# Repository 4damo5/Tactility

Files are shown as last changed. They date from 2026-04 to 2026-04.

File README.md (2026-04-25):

# Tactility: The Portable Braille Reader
*Knowledge at Your Fingertips* · Forge Hardware Spring 2026 · Northeastern University

---

Tactility is a handheld Braille reading device that converts digital text into tactile output in real time. Existing refreshable Braille displays cost hundreds to thousands of dollars and are rarely portable, while Tactility is designed to be compact and affordable.

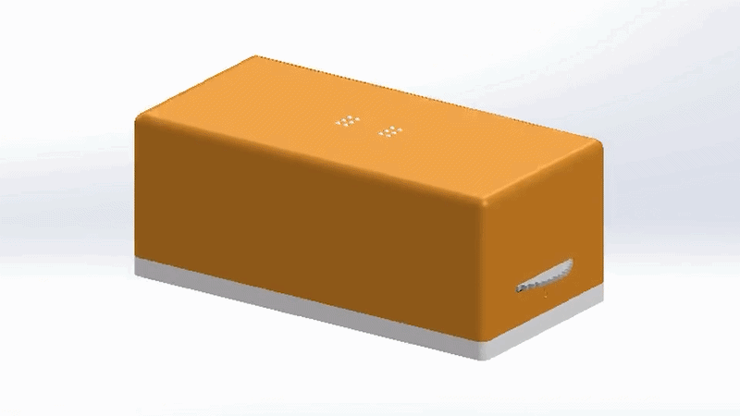
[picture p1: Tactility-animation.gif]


## The Team

| Name | Team |
|---|---|
| Adam Otsuka | Lead |
| Alexandre Lannibois | ECE |
| Daniel Brightman | ECE |
| Ibrahim Rogers | ME |
| Mary Morris | ECE |
| Ryan Heberlig | ME |
| Supratim Shaud | ME |

## How It Works

A rack-and-pinion mechanism drives 6 pins per Braille cell using N20 gearbox motors. An ESP32 microcontroller runs a PDF → text → Braille pipeline, mapping each character to a 6-pin binary array and actuating the motors accordingly. Navigation is handled via scroll wheel, push buttons, and vibration feedback. The PCB was designed in Altium.

## Prototypes

Five iterations were built over the semester, starting with a breadboard proof-of-concept and ending with a 2-cell showcase model with a custom PCB. The ideal form factor is a snap-fit handheld case with Tactility's orange-and-white branding.

## Future Work

- Electromagnetic pin system for a smaller footprint
- MagSafe induction charging for single-hand use
- Phone case form factor
- Companion app for cross-platform text input

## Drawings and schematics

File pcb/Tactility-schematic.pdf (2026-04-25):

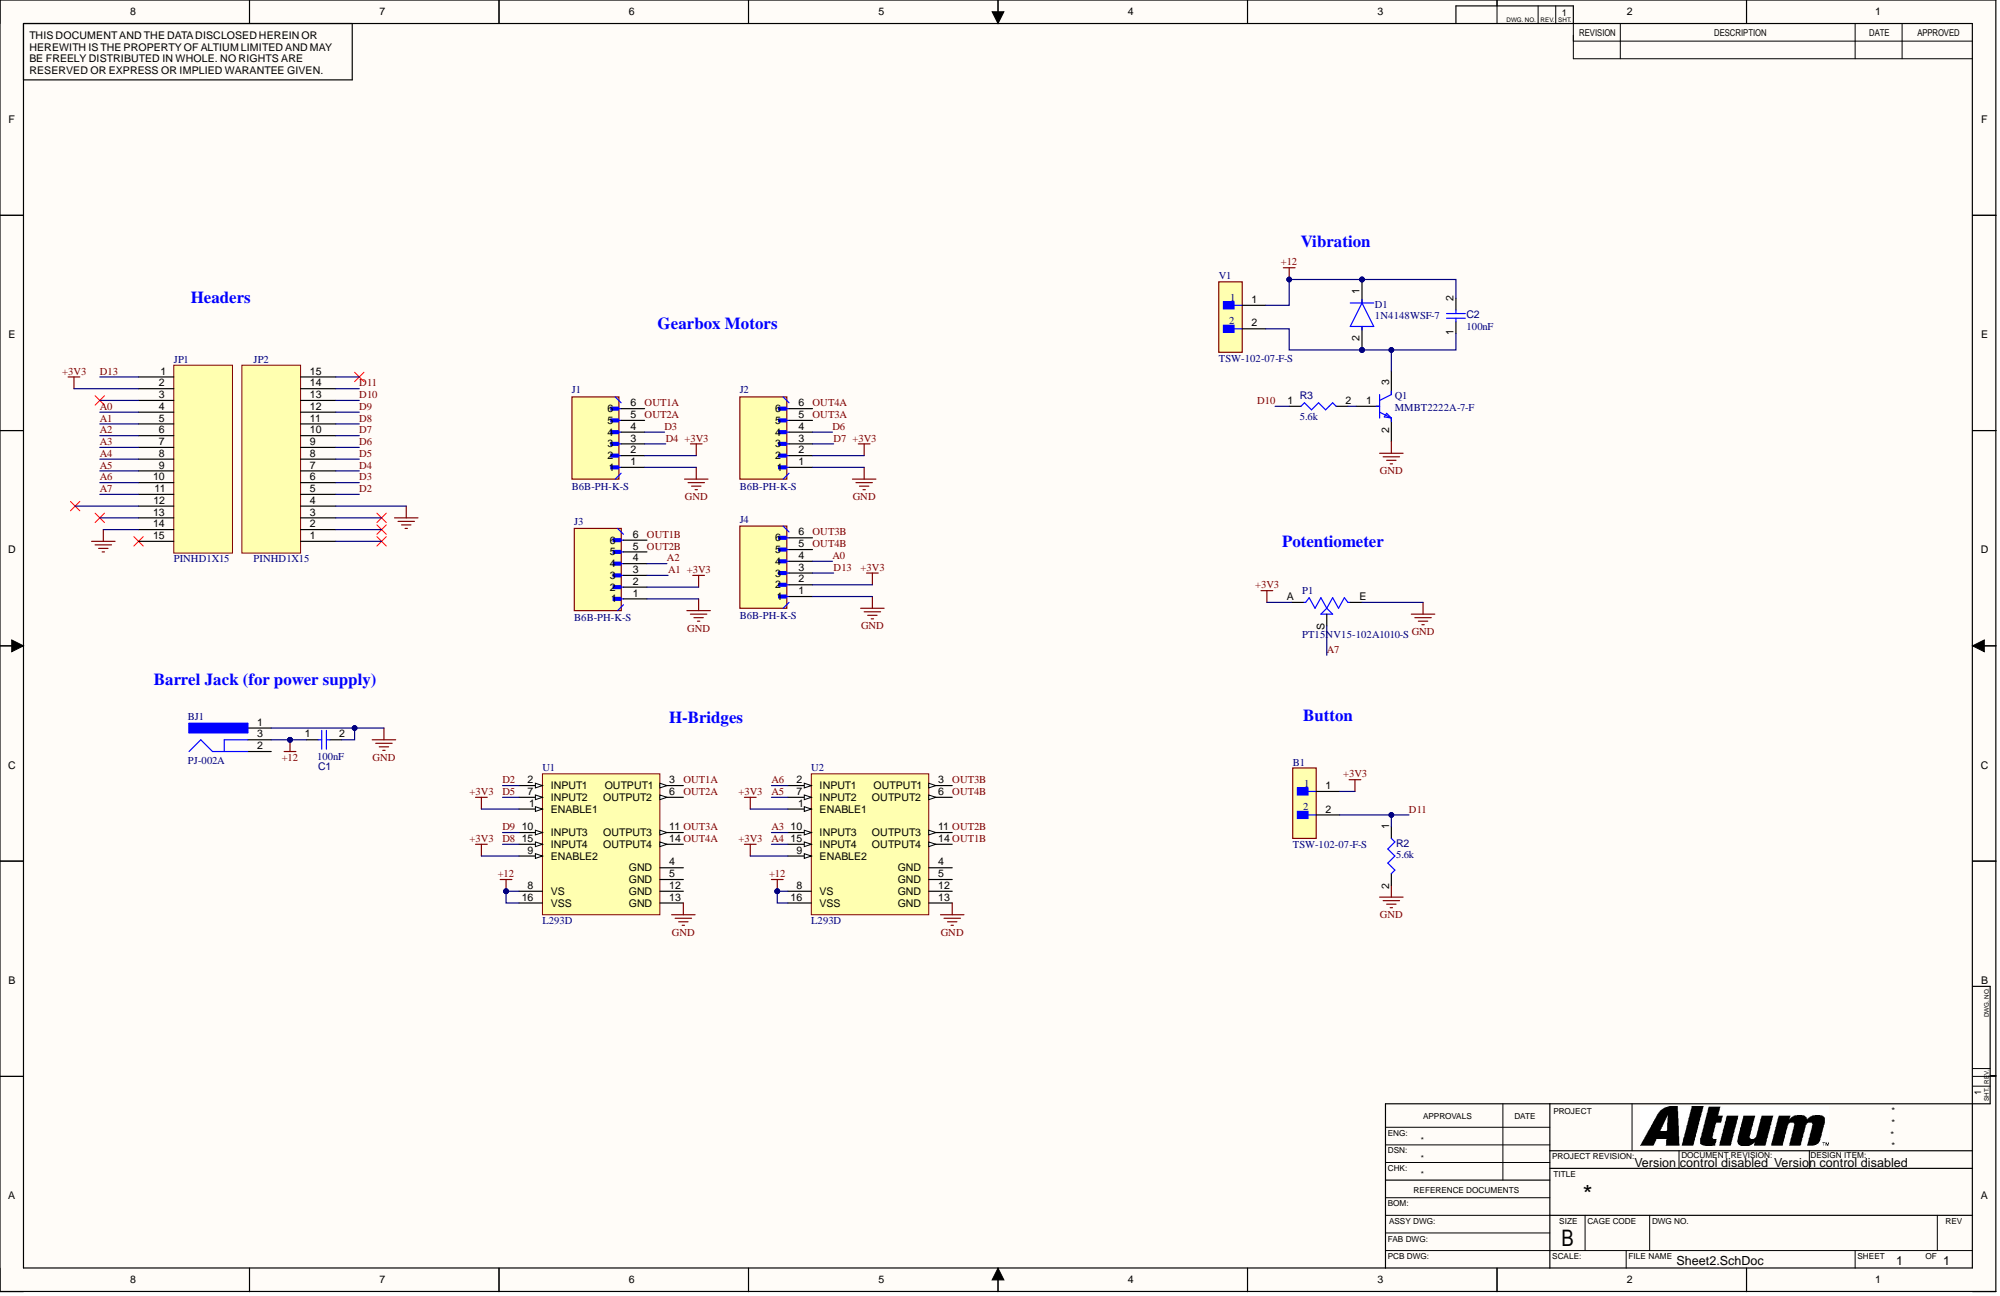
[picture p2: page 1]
SIZE; DWG NO; FILE NAM; CAGE CODE; REFERENCE DOCUMENTS; ASSY DWG; FAB DWG; PCB DWG; x Motors; VSS 16; INPU; Barrel J; ack (fo; r power supply; B1 TSW-1

DWG . N O . | R E V | 1 . S H T.

T H IS DOC U MEN T AN D T HE D ATA D ISCLOSED HEREI N OR HEREW I T H IS T HE PROPER TY OF ALT I U M LI M I TED AN D M AY BE F REELY D IST R IBU TED I N W HOLE. NO R IGH TS ARE RESERVED OR EXPRESS OR TEE GIVEN I MPLIED WARAN . | Vibratio n +1 2 | REVISI O N | DESCRIPTI O N | DATE | APPROVED

REV. SHT. DWG. NO.

DATE | PRO JECT | **** APPROVALS

ENG : **

DSN:

PRO JECT REVISION: Version | DOCUMENT REVISION: control disabled Version control disabled | DESIGN ITEM :

CHK: *

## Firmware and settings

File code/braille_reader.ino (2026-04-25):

#include "braille_dictionary.h"
#include "braille_cell.h"

// -------------------- PIN ALLOCATION --------------------

// Motor 0 — Cell 1 Left
const int EN_PIN[4]  = { D5, 18, 25, 15 };
const int IN1_PIN[4] = { D6, 19, 33,  4 };
const int IN2_PIN[4] = { D7, 21, 32, 16 };

// Encoders
const int ENC_A[4]   = { D2, 22, 13, 17 };
const int ENC_B[4]   = { D3, 26, 14,  5 };

// Motor index labels for readability
// 0 = Cell 1 Left
// 1 = Cell 1 Right
// 2 = Cell 2 Left
// 3 = Cell 2 Right

// -------------------- MOTOR CALIBRATION --------------------
long POS8_COUNTS = 3000;
const int ENCODER_SIGN = -1;

// -------------------- TUNING --------------------
const int GO_PWM         = 35;
const int TOLERANCE      = 8;
const int MOVE_TIMEOUT   = 8000;
const int BRAKE_MS       = 80;
const int BACKOFF_COUNTS = 20;
const int SLOW_PWM       = 35;
const int SLOW_ZONE      = 25;
const int STABLE_MS      = 120;
const int STABLE_DELAY   = 20;

// -------------------- ENCODER --------------------
volatile long rawEncoderCount[4] = {0, 0, 0, 0};
volatile uint8_t lastEncoded[4]  = {0, 0, 0, 0};

const int8_t quadTable[16] = {
    0, -1,  1,  0,
    1,  0,  0, -1,
   -1,  0,  0,  1,
    0,  1, -1,  0
};

void IRAM_ATTR updateEncoderN(int n) {
    uint8_t a = digitalRead(ENC_A[n]);
    uint8_t b = digitalRead(ENC_B[n]);
    uint8_t encoded = (a << 1) | b;
    uint8_t sum = (lastEncoded[n] << 2) | encoded;
    rawEncoderCount[n] += quadTable[sum];
    lastEncoded[n] = encoded;
}

void IRAM_ATTR updateEncoder0() { updateEncoderN(0); }
void IRAM_ATTR updateEncoder1() { updateEncoderN(1); }
void IRAM_ATTR updateEncoder2() { updateEncoderN(2); }
void IRAM_ATTR updateEncoder3() { updateEncoderN(3); }

long getEncoderCount(int n) {
    noInterrupts();
    long c = rawEncoderCount[n];
    interrupts();
    return c * ENCODER_SIGN;
    
}


class BrailleQueue {
    private:
        static const int cap = 2;
        BrailleCell* arr[cap];
        int count;

    public:
        BrailleQueue() : count(0) {
            for (int i = 0; i < cap; i++) arr[i] = nullptr;
        }

        int getCount() const { return count; }
        void setCount(int i) { count = i; }
        int getCap() { return cap; }

        BrailleCell getIndex(int displayPos) const {
            int filled = (count < cap) ? count : cap;
            int oldest = (count - filled) % cap;
            BrailleCell* cell = arr[(oldest + displayPos) % cap];
            if (cell == nullptr) return BrailleCell();
            return *cell;
        }

        bool isEmpty() const { return count == 0; }
        void increaseCount() { count += 1; }
        void decreaseCount() { count -= 1; }

        void forward(char c) {
            int slot = count % cap;
            if (arr[slot] == nullptr) arr[slot] = new BrailleCell();
            arr[slot]->setLetter(c);
            count++;
        }

        void backward(char c) {
            count--;
            int slot = count % cap;
            arr[slot]->setLetter(c);
        }

        void empty() {
            this->count = 0;
            for (int i = 0; i < cap; i++) {
                delete arr[i];
                arr[i] = nullptr;
            }
        }

        void printOut() {
            for (int i = 0; i < cap; i++) {
                if (arr[i] != nullptr) {
                    Serial.print(arr[i]->getLetter());
                    Serial.print(" | ");
                }
            }
            Serial.println(" ");
        }

        void addLine(String input) {
            if (input.length() > cap) {
                Serial.println("addLine Error - too long");
                return;
            }
            for (int i = 0; i < input.length(); i++) {
                if (arr[i] == nullptr) arr[i] = new BrailleCell();
                arr[i]->setLetter(input[i]);
            }
        }
};

// -------------------- MOTOR CONTROL --------------------
void setMotor(int pwm, int dir, int n) {
    pwm = constrain(pwm, 0, 255);
    if (dir > 0) {
        digitalWrite(IN1_PIN[n], LOW);
        digitalWrite(IN2_PIN[n], HIGH);
    } else if (dir < 0) {
        digitalWrite(IN1_PIN[n], HIGH);
        digitalWrite(IN2_PIN[n], LOW);
    } else {
        digitalWrite(IN1_PIN[n], LOW);
        digitalWrite(IN2_PIN[n], LOW);
        pwm = 0;
    }
    analogWrite(EN_PIN[n], pwm);
}

void stopMotor(int n) {
    digitalWrite(IN1_PIN[n], LOW);
    digitalWrite(IN2_PIN[n], LOW);
    analogWrite(EN_PIN[n], 0);
}

void holdBrake(int n) {
    digitalWrite(IN1_PIN[n], HIGH);
    digitalWrite(IN2_PIN[n], HIGH);
    analogWrite(EN_PIN[n], 255);
}

void brakeAndHold(int n) {
    holdBrake(n);
    delay(BRAKE_MS);
    holdBrake(n);
}

void releaseBrake(int n) {
    stopMotor(n);
}

// -------------------- MOVEMENT --------------------
void moveToTargetDirect(long target, int n) {
    unsigned long startTime = millis();
    unsigned long stableStart = 0;

    while (true) {
        long current = getEncoderCount(n);
        long error = target - current;
        long absError = abs(error);

        Serial.print("Motor "); Serial.print(n);
        Serial.print("  Current: "); Serial.print(current);
        Serial.print("  Target: "); Serial.print(target);
        Serial.print("  Error: "); Serial.println(error);

        if (absError <= TOLERANCE) {
            brakeAndHold(n);
            if (stableStart == 0) stableStart = millis();
            if (millis() - stableStart >= STABLE_MS) {
                Serial.print("Motor "); Serial.print(n); Serial.println(" reached target");
                return;
            }
            delay(STABLE_DELAY);
        } else {
            stableStart = 0;
            int pwm = (absError <= SLOW_ZONE) ? SLOW_PWM : GO_PWM;
            if (error > 0) setMotor(pwm,  1, n);
            else           setMotor(pwm, -1, n);
            delay(8);
        }

        if (millis() - startTime > MOVE_TIMEOUT) {
            brakeAndHold(n);
            Serial.print("Motor "); Serial.print(n); Serial.println(" timeout");
            return;
        }
    }
}

void moveToAbsolutePosition(long target, int n) {
    long current = getEncoderCount(n);

    if (current > target) {
        long backoffTarget = target - BACKOFF_COUNTS;
        if (backoffTarget < 0) backoffTarget = 0;
        Serial.print("Motor "); Serial.print(n);
        Serial.print(" backing off to "); Serial.println(backoffTarget);
        releaseBrake(n);
        moveToTargetDirect(backoffTarget, n);
    }

    Serial.print("Motor "); Serial.print(n);
    Serial.print(" final approach to "); Serial.println(target);
    releaseBrake(n);
    moveToTargetDirect(target, n);
    Serial.print("Motor "); Serial.print(n); Serial.println(" holding position");
}

void goToPosition(int pos, int n) {
    if (pos < 1 || pos > 8) return;
    long target = (POS8_COUNTS * pos) / 8;
    Serial.print("Motor "); Serial.print(n);
    Serial.print(" going to position "); Serial.print(pos);
    Serial.print("  target = "); Serial.println(target);
    moveToAbsolutePosition(target, n);
}

// -------------------- ZERO --------------------
void setZeroAll() {
    noInterrupts();
    for (int i = 0; i < 4; i++) rawEncoderCount[i] = 0;
    interrupts();
    Serial.println("All encoders zeroed");
}

// -------------------- ANGLES --------------------
// Index 0-7 maps 3-bit dot column pattern to motor position 1-8
const int angles[8] = {1, 2, 3, 4, 5, 6, 7, 8};

// -------------------- POTENTIOMETER & BUTTON --------------------
const int potPin   = A3;
const int buttonPin = 12;

int potVal   = 0;
int speed    = 0;
int oldSpeed = 0;
const int maxSpeed = 255;

int delayTime = 1250;
unsigned long previousMillis = 0;

byte lastButtonState = HIGH;
bool isPaused = false;
unsigned long debounceDuration = 50;
unsigned long lastTimeButtonChanged = 0;

int changeReadingSpeed(int speedInput) {
    int givenSpeed = abs(250 - speedInput);
    return map(givenSpeed, 0, 250, 1000, 5000);
}

void readPotentiometer() {
    oldSpeed = speed;
    potVal = analogRead(potPin);
    speed = constrain(map(potVal, 0, 720, 0, maxSpeed), 0, maxSpeed);
    if (oldSpeed != speed) {
        Serial.print("Potentiometer: "); Serial.println(potVal);
        Serial.print("New Speed: "); Serial.println(speed);
        delayTime = changeReadingSpeed(speed);
    }
}

void readPauseButton() {
    if (millis() - lastTimeButtonChanged > debounceDuration) {
        byte buttonState = digitalRead(buttonPin);
        if (buttonState != lastButtonState) {
            lastTimeButtonChanged = millis();
            lastButtonState = buttonState;
            if (buttonState == LOW) {
                isPaused = !isPaused;
                Serial.print("Paused: ");
                Serial.println(isPaused ? "YES" : "NO");
            }
        }
    }
}

// -------------------- BRAILLE DISPLAY --------------------
void printPattern(std::vector<std::vector<int>> pattern) {
    for (int row = 0; row < pattern.size(); row++) {
        for (int col = 0; col < pattern[row].size(); col++) {
            Serial.print(pattern[row][col]);
            Serial.print(" | ");
        }
        Serial.println();
    }
}

// -------------------- OBJECTS --------------------
BrailleCell* braille;
BrailleQueue* queue;
String input = "";
int charIndex = 0;
bool processing = false;

// -------------------- SETUP --------------------
void setup() {
    Serial.begin(115200);
    pinMode(buttonPin, INPUT_PULLUP);

    for (int i = 0; i < 4; i++) {
        pinMode(EN_PIN[i],  OUTPUT);
        pinMode(IN1_PIN[i], OUTPUT);
        pinMode(IN2_PIN[i], OUTPUT);
        pinMode(ENC_A[i], INPUT_PULLUP);
        pinMode(ENC_B[i], INPUT_PULLUP);
        stopMotor(i);

        uint8_t a = digitalRead(ENC_A[i]);
        uint8_t b = digitalRead(ENC_B[i]);
        lastEncoded[i] = (a << 1) | b;
    }

    attachInterrupt(digitalPinToInterrupt(ENC_A[0]), updateEncoder0, CHANGE);
    attachInterrupt(digitalPinToInterrupt(ENC_A[1]), updateEncoder1, CHANGE);
    attachInterrupt(digitalPinToInterrupt(ENC_A[2]), updateEncoder2, CHANGE);
    attachInterrupt(digitalPinToInterrupt(ENC_A[3]), updateEncoder3, CHANGE);

    setZeroAll();

    braille = new BrailleCell();
    queue   = new BrailleQueue();

    while (!Serial);
    Serial.println("Enter a word:");
}

// -------------------- MAIN LOOP --------------------
void loop() {
    readPauseButton();
    readPotentiometer();

    int cap = queue->getCap();
    unsigned long currentMillis = millis();

    // INPUT SECTION
    if (Serial.available() > 0 && !processing) {
        input = Serial.readStringUntil('\n');
        input.trim();
        Serial.println("You entered: " + input);
        charIndex = 0;
        processing = true;
    }

    // PROCESSING SECTION
    if (processing) {
        if (!isPaused) {
            if (currentMillis - previousMillis >= delayTime) {
                previousMillis = currentMillis;

                if (charIndex < input.length()) {
                    String chunk;

                    if (::isUpper(input[charIndex])) {
                        chunk = input.substring(charIndex, charIndex + 1);
                        charIndex += 1;
                    } else {
                        chunk = input.substring(charIndex, charIndex + cap);
                        charIndex += cap;
                    }

                    Serial.print("Chunk: ");
                    Serial.println(chunk);

                    queue->empty();
                    queue->addLine(chunk);

                    std::vector<std::vector<int>> pattern1 = queue->getIndex(0).getPattern();
                    std::vector<std::vector<int>> pattern2 = queue->getIndex(1).getPattern();

                    if (queue->getIndex(0).isUpperCase()) {
                        // Capital indicator on cell 1, uppercase letter on cell 2
                        std::vector<std::vector<int>> capIndicator = {{0,0}, {0,0}, {0,1}};

                        int c1L = braille->getCase(angles, 'L', capIndicator);
                        int c1R = braille->getCase(angles, 'R', capIndicator);
                        int c2L = braille->getCase(angles, 'L', pattern1);
                        int c2R = braille->getCase(angles, 'R', pattern1);

                        goToPosition(c1L, 0); // Cell 1 Left
                        goToPosition(c1R, 1); // Cell 1 Right
                        goToPosition(c2L, 2); // Cell 2 Left
                        goToPosition(c2R, 3); // Cell 2 Right

                        Serial.println("Cell 1 (capital indicator):");
                        printPattern(capIndicator);
                        Serial.println("-----------");
                        Serial.println("Cell 2:");
                        printPattern(pattern1);

                    } else {
                        int c1L = braille->getCase(angles, 'L', pattern1);
                        int c1R = braille->getCase(angles, 'R', pattern1);
                        int c2L = braille->getCase(angles, 'L', pattern2);
                        int c2R = braille->getCase(angles, 'R', pattern2);

                        goToPosition(c1L, 0); // Cell 1 Left
                        goToPosition(c1R, 1); // Cell 1 Right
                        goToPosition(c2L, 2); // Cell 2 Left
                        goToPosition(c2R, 3); // Cell 2 Right

                        Serial.println("Cell 1:");
                        printPattern(pattern1);
                        Serial.println("-----------");
                        Serial.println("Cell 2:");
                        printPattern(pattern2);
                    }

                } else {
                    processing = false;
                    charIndex = 0;
                    Serial.println("Enter a word:");
                }
            }
        } else {
            readPauseButton();
        }
    }
}
